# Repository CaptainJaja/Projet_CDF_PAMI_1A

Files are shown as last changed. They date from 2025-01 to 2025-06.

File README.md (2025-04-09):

# 🤖 Projet Coupe de France de Robotique 2025 – Design PCB 4 couches et Code STM32

Bienvenue sur le dépôt dédié à mon **design de PCB 4 couches** réalisé dans le cadre de la **Coupe de France de Robotique 2025** organisée par Planète Sciences.  
👉 [Site officiel](https://www.coupederobotique.fr/)

Je participe à cette aventure en tant qu'étudiant de **première année à l'ENSEA**, au sein de l'association **ARES Robotique**, avec une équipe composée également de deuxièmes années.

---

## 🧩 Description du PCB

Ce PCB a été conçu pour les **PAMI** (*Petits Actionneurs Mobiles Indépendants*), et intègre les fonctionnalités suivantes :

- 🧠 **Microcontrôleur :** STM32 L552CCT6
- ⚙️ **Driver moteur :** TB6612FNG
- 🚗 **2 connecteurs pour moteurs DC N20**
- 🔁 **2 connecteurs pour servomoteurs**
- 🧭 **1 connecteur pour module ultrason** (détection et évitement d'obstacles)
- ⚫ **1 connecteur pour module suiveur de ligne infrarouge 4 voies**
- 🔘 **Bouton reset**
- 🔌 **Pins GPIO, 3.3V, GND**
- 🔋 **Connecteur alimentation 7.4V (batterie Ni-Mh)**
- 🔧 **2 régulateurs DC-DC** (5V et 3.3V)
- 🔁 **Bobines, condensateurs, résistances**
- 🛠️ **Connecteur ST-Link** pour programmation et debug

---

## 🎬 Démos en GIF

### 🔩 PCB assemblé avec les composants soudés
GIF0 - Suiveur de ligne

### 🚗 Suiveur de ligne en action
GIF1 - PCB assemblé

---

## 🖼️ Vues des 4 couches du PCB

| Couche | Image |
|---|---|
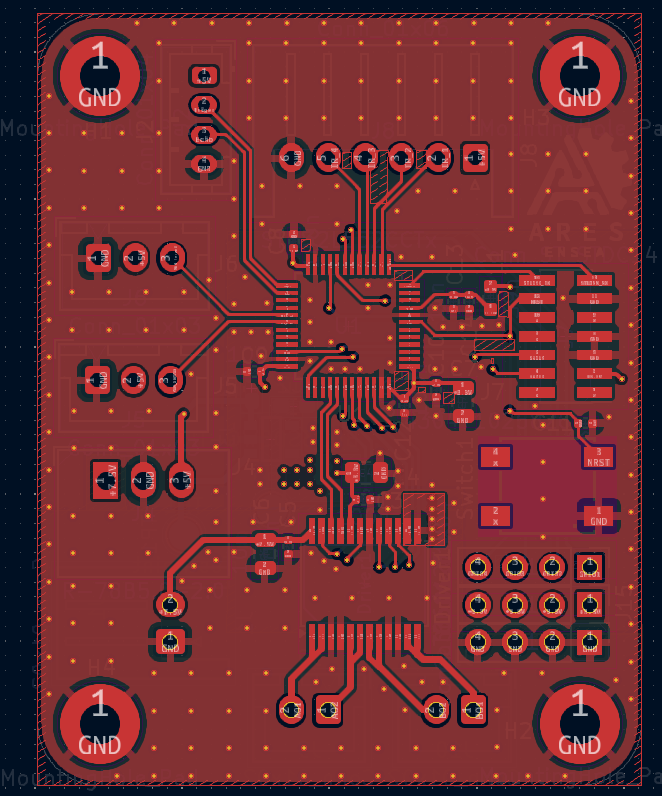
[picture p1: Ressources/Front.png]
Front
| **Face avant (Front)** |  |
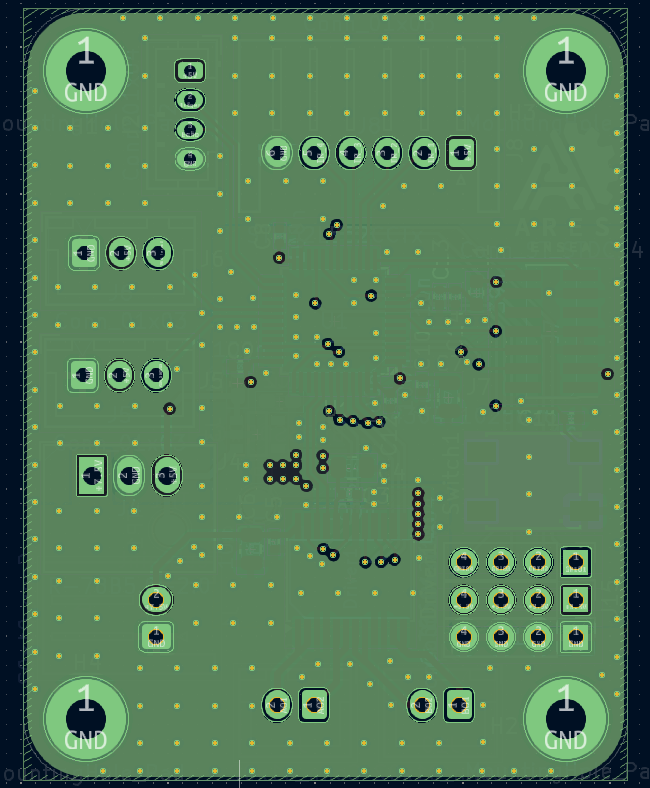
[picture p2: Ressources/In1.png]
In1
| **Plan de masse (In1)** |  |
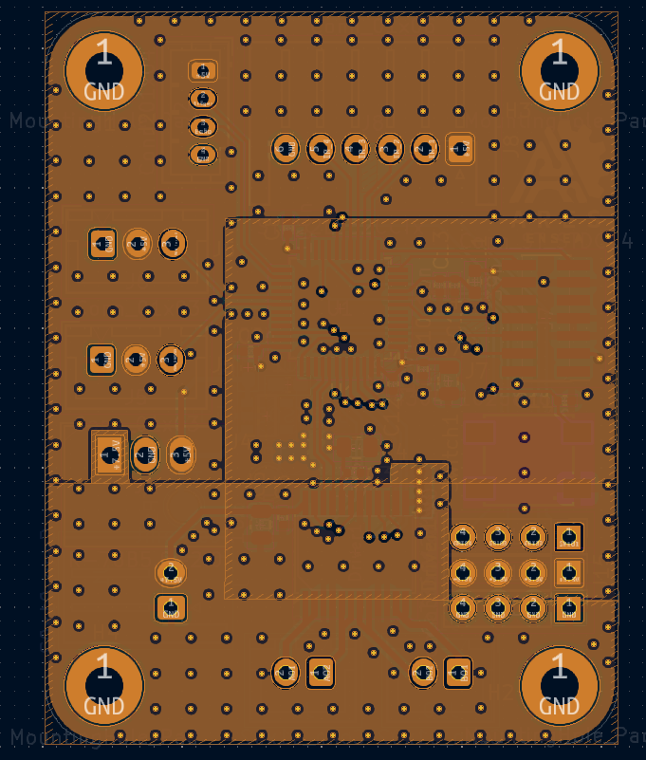
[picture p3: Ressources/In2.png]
In2
| **Plan d'alimentation (In2)** |  |
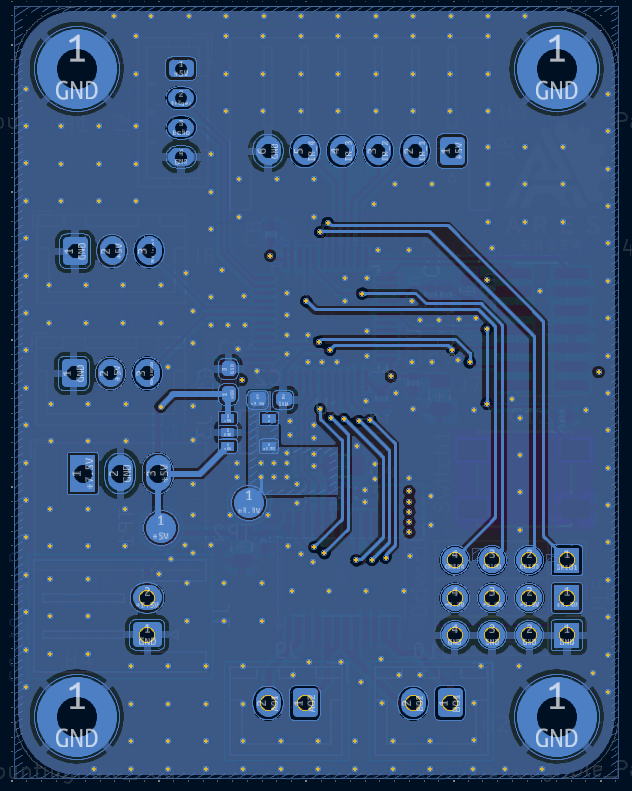
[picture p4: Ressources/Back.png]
Back
| **Face arrière (Back)** |  |

---

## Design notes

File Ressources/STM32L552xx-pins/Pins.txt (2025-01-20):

pour le STM32L552 en boîtier LQFP48 :

ADC12 : 
	   Pin num ; Pin name
* IN5= 		10 ; PA0
* IN6= 		11 ; PA1
* IN7= 		12 ; PA2
* IN8= 		13 ; PA3
* IN9= 		14 ; PA4
* IN10= 	15 ; PA5
* IN11= 	16 ; PA6
* IN12= 	17 ; PA7
* IN15= 	18 ; PB0
* IN16= 	19 ; PB1

Timers :
	   Pin num ; Pin name
*TIM2_CH1=	10 ; PA0 	(TIM5_CH1, USART, UART4_TX)
*TIM2_CH1=	15 ; PA5	(TIM2_ETR, TIM8_CH1N)
*TIM2_CH2=	11 ; PA1	(TIM5_CH2)
*TIM2_CH3=	12 ; PA2	(TIM5_CH3, TIM15_CH1, USART2_TX)
*TIM2_CH4=	13 ; PA3	(TIM5_CH4, TIM15_CH2, USART2_RX)
*TIM3_CH1=	16 ; PA6	(TIM1_BKIN, TIM8_BKIN, TIM16_CH1)
*TIM3_CH2=	17 ; PA7	(TIM1_CH1N, TIM8_CH1N, TIM17, CH1)
*TIM3_CH3=	18 ; PB0	(TIM1_CH2N, TIM8_CH2N)
*TIM3_CH4=	19 ; PB1	(TIM1_CH3N, TIM8_CH3N)
*TIM15_CH1=	27 ; PB14	(TIM1_CH2N, TIM8_CH2N)
*TIM1_CH1=	29 ; PA8	
*TIM1_CH2=	30 ; PA9
*TIM1_CH3=	31 ; PA10
*TIM1_CH4=	32 ; PA11
*TIM1_ETR=	33 ; PA12

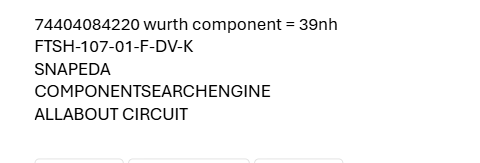
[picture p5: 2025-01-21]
Ressources/mail patricia.png

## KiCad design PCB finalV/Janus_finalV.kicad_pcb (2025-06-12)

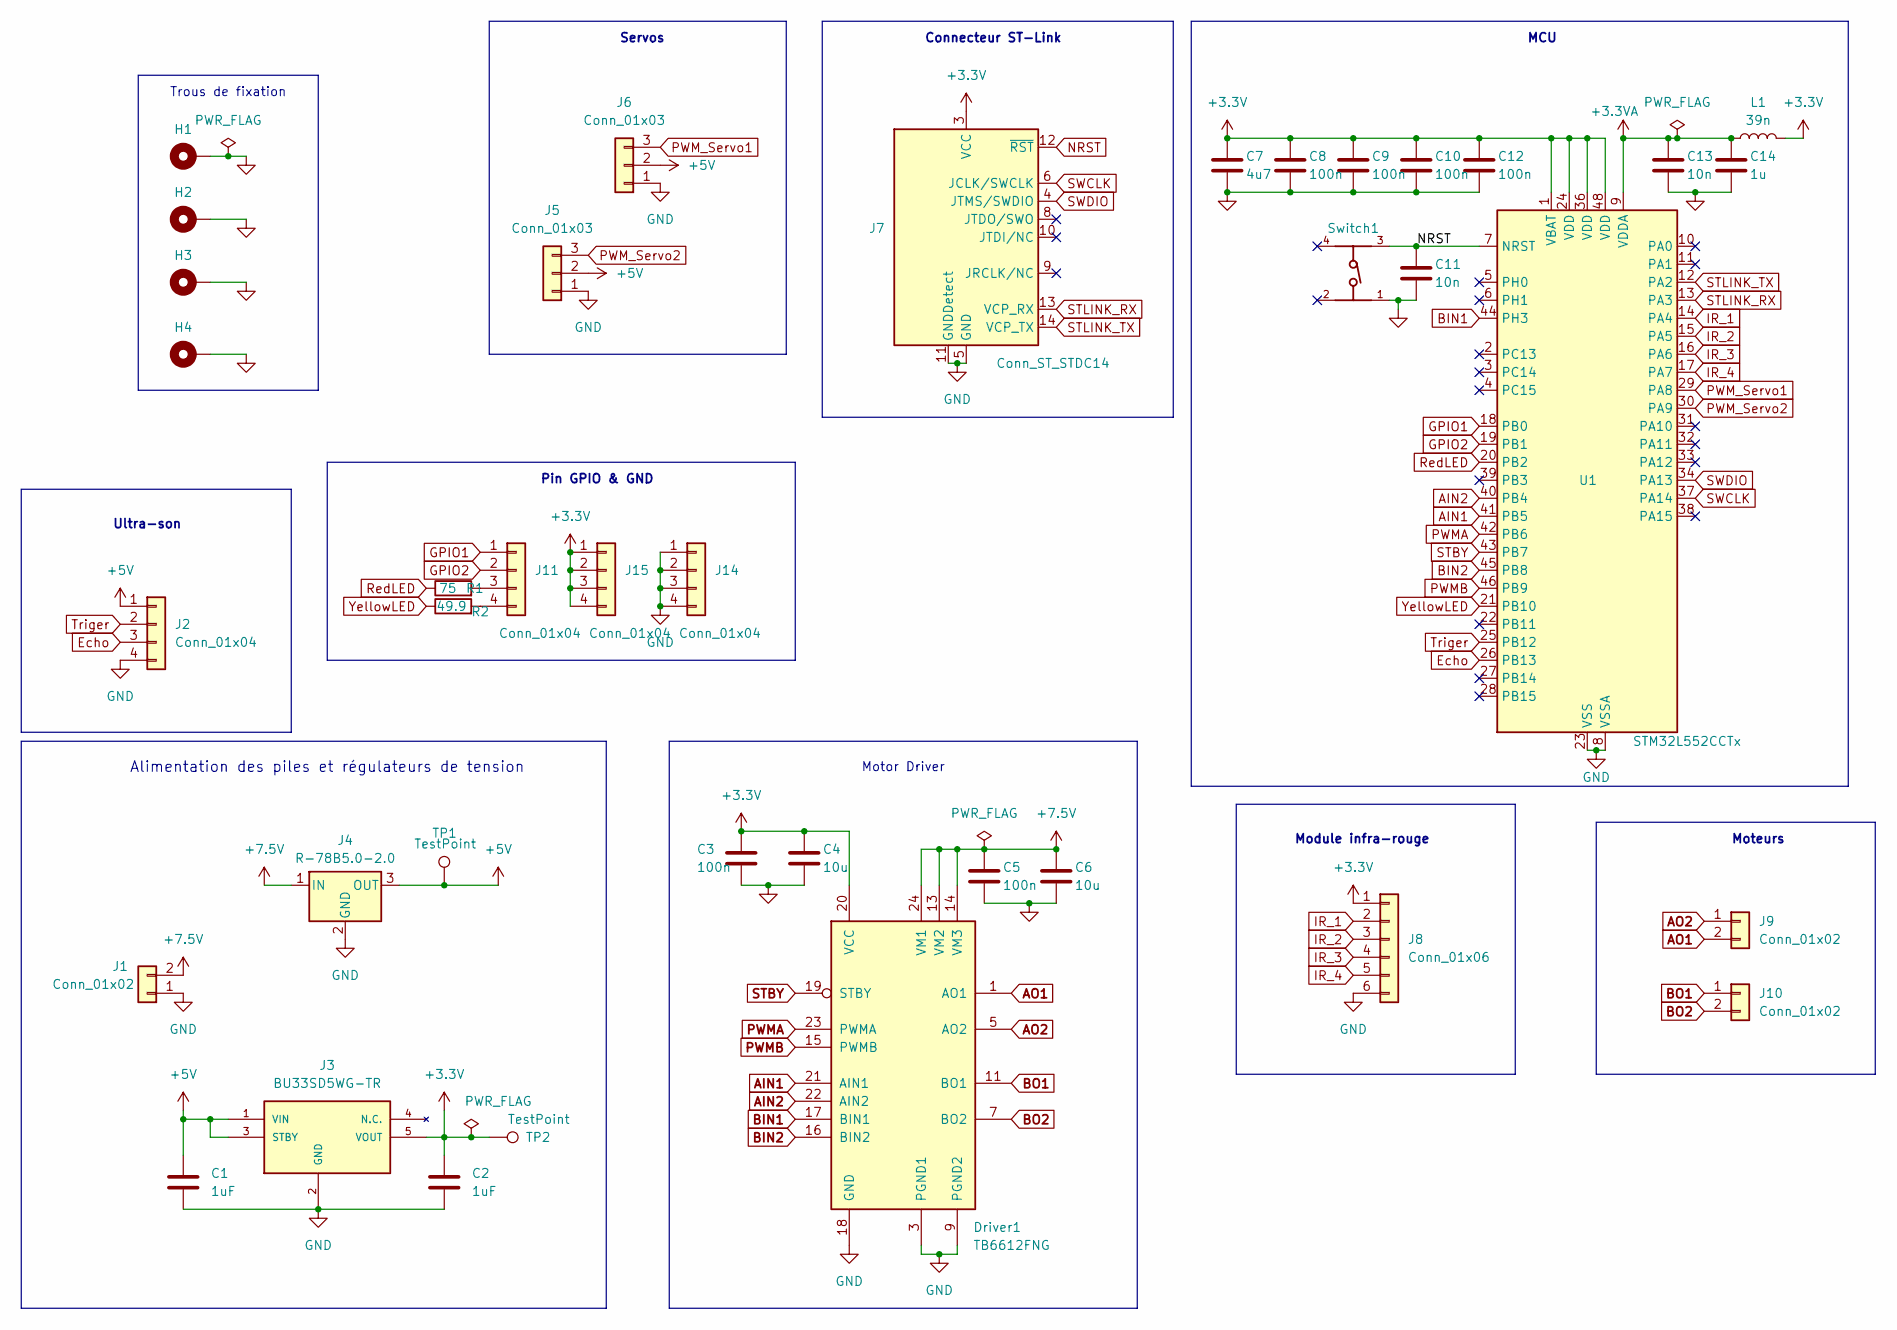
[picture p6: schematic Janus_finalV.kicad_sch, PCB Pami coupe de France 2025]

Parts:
C1, C2: 1uF; C_0603_1608Metric_Pad1.08x0.95mm_HandSolder
C3, C5, C8, C9, C10, C12: 100n; C_0402_1005Metric
C4, C6: 10u; C_0805_2012Metric
C7: 4u7; C_0805_2012Metric
C11, C13: 10n; C_0402_1005Metric
C14: 1u; C_0402_1005Metric
Driver1: TB6612FNG; SSOP-24_5.3x8.2mm_P0.65mm
H1, H2, H3, H4: MountingHole_Pad; MountingHole_2.7mm_M2.5_Pad
J1: Conn_01x02; JST_XH_S2B-XH-A-1_1x02_P2.50mm_Horizontal
J2: Conn_01x04; JST_PH_B4B-PH-K_1x04_P2.00mm_Vertical
J3: BU33SD5WG-TR; SOT95P280X125-5N; Mouser_Part_Number 755-BU33SD5WG-TR
J4: R-78B5.0-2.0; Converter_DCDC_RECOM_R-78B-2.0_THT
J5, J6: Conn_01x03; JST_XH_B3B-XH-A_1x03_P2.50mm_Vertical
J7: Conn_ST_STDC14; PinHeader_2x07_P1.27mm_Vertical_SMD
J8: Conn_01x06; JST_XH_S6B-XH-A-1_1x06_P2.50mm_Horizontal
J9, J10: Conn_01x02; JST_XH_B2B-XH-A_1x02_P2.50mm_Vertical
J11, J14, J15: Conn_01x04; PinHeader_1x04_P2.54mm_Vertical
L1: 39n; L_0603_1608Metric
R1: 75; R_0402_1005Metric_Pad0.72x0.64mm_HandSolder
R2: 49.9; R_0402_1005Metric_Pad0.72x0.64mm_HandSolder
Switch1: 430471025826; PART-NUMBER 430471025826
TP1, TP2: TestPoint; TestPoint_Pad_D2.0mm
U1: STM32L552CCTx; LQFP-48_7x7mm_P0.5mm

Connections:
+3.3V: C2.1, C3.1, C4.1, C7.1, C8.1, C9.1, C10.1, C12.1, Driver1.20 (VCC), J3.5 (VOUT), J7.3 (VCC), J8.1, J15.1, J15.2, J15.3, J15.4, L1.2, TP2.1, U1.1 (VBAT), U1.24 (VDD), U1.36 (VDD), U1.48 (VDD)
+3.3VA: C13.1, C14.1, L1.1, U1.9 (VDDA)
+5V: C1.1, J2.1, J3.1 (VIN), J3.3 (STBY), J4.3 (OUT), J5.2, J6.2, TP1.1
+7.5V: C5.1, C6.1, Driver1.13 (VM2), Driver1.14 (VM3), Driver1.24 (VM1), J1.2, J4.1 (IN)
AIN1: Driver1.21 (AIN1), U1.41 (PB5)
AIN2: Driver1.22 (AIN2), U1.40 (PB4)
AO1: Driver1.1 (AO1), Driver1.2 (AO1), J9.2
AO2: Driver1.5 (AO2), Driver1.6 (AO2), J9.1
BIN1: Driver1.17 (BIN1), U1.44 (PH3)
BIN2: Driver1.16 (BIN2), U1.45 (PB8)
BO1: Driver1.11 (BO1), Driver1.12 (BO1), J10.1
BO2: Driver1.7 (BO2), Driver1.8 (BO2), J10.2
Echo: J2.3, U1.26 (PB13)
GND: C1.2, C2.2, C3.2, C4.2, C5.2, C6.2, C7.2, C8.2, C9.2, C10.2, C11.2, C12.2, C13.2, C14.2, Driver1.3 (PGND1), Driver1.4 (PGND1), Driver1.9 (PGND2), Driver1.10 (PGND2), Driver1.18 (GND), H1.1, H2.1, H3.1, H4.1, J1.1, J2.4, J3.2 (GND), J4.2 (GND), J5.1, J6.1, J7.5 (GND), J7.7 (GND), J7.11 (GNDDetect), J8.6, J14.1, J14.2, J14.3, J14.4, Switch1.1, U1.8 (VSSA), U1.23 (VSS), U1.35 (VSS), U1.47 (VSS)
GPIO1: J11.1, U1.18 (PB0)
GPIO2: J11.2, U1.19 (PB1)
IR_1: J8.2, U1.14 (PA4)
IR_2: J8.3, U1.15 (PA5)
IR_3: J8.4, U1.16 (PA6)
IR_4: J8.5, U1.17 (PA7)
NRST: C11.1, J7.12 (~RST), Switch1.3, U1.7 (NRST)
unnamed: J11.3, R1.2
unnamed: J11.4, R2.2
PWMA: Driver1.23 (PWMA), U1.42 (PB6)
PWMB: Driver1.15 (PWMB), U1.46 (PB9)
PWM_Servo1: J6.3, U1.29 (PA8)
PWM_Servo2: J5.3, U1.30 (PA9)
RedLED: R1.1, U1.20 (PB2)
STBY: Driver1.19 (STBY), U1.43 (PB7)
STLINK_RX: J7.13 (VCP_RX), U1.13 (PA3)
STLINK_TX: J7.14 (VCP_TX), U1.12 (PA2)
SWCLK: J7.6 (JCLK/SWCLK), U1.37 (PA14)
SWDIO: J7.4 (JTMS/SWDIO), U1.34 (PA13)
Triger: J2.2, U1.25 (PB12)
YellowLED: R2.1, U1.21 (PB10)

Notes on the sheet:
Trous de fixation
Servos
Moteurs
Module infra-rouge
Connecteur ST-Link
Ultra-son
Alimentation des piles et régulateurs de tension
Motor Driver
Pin GPIO & GND
MCU

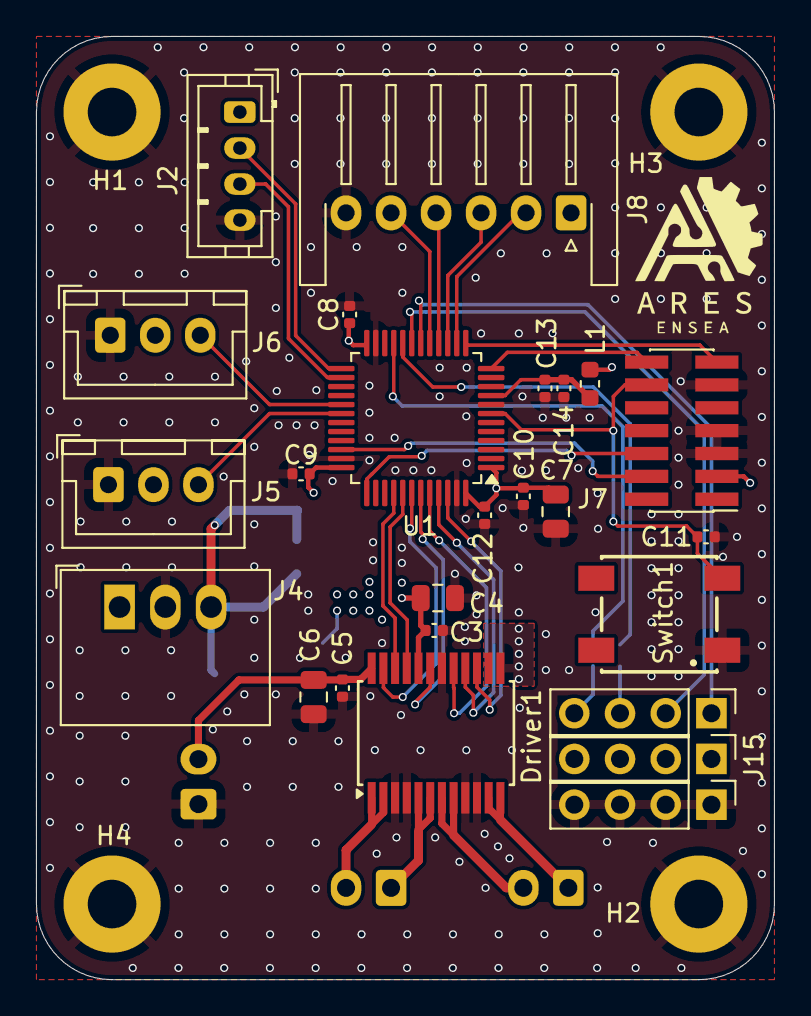
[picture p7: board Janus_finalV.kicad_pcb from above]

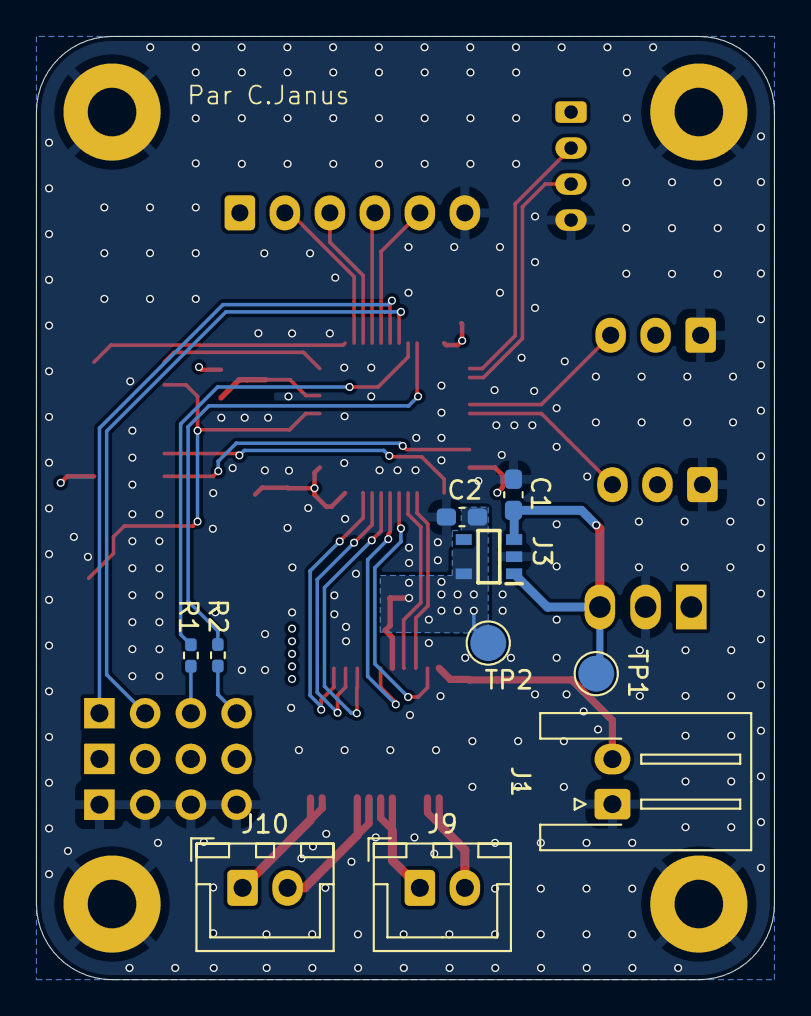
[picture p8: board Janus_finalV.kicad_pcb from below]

Board: 4 copper layers, 41.0 x 52.4 mm, 39 parts (10 on the bottom side), 35 nets.

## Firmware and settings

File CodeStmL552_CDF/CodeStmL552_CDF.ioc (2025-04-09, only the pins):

Mcu.UserName=STM32L552CCTx
PA2.Signal=USART2_TX
PA3.Signal=USART2_RX
PA4.GPIO_Label=X1
PA4.Signal=ADCx_IN9
PA5.GPIO_Label=X2
PA5.Signal=ADCx_IN10
PA6.GPIO_Label=X3
PA6.Signal=ADCx_IN11
PA7.GPIO_Label=X4
PA7.Signal=ADCx_IN12
PA8.GPIO_Label=Servo2
PA8.Signal=S_TIM1_CH1
PA9.GPIO_Label=Servo1
PA9.Signal=S_TIM1_CH2
PB0.GPIO_Label=Button
PB0.Signal=GPXTI0
PB12.GPIO_Label=TRIG
PB12.Signal=GPIO_Output
PB13.GPIO_Label=ECHO
PB13.Signal=GPXTI13
PB5.GPIO_Label=AIN1
PB5.Signal=GPIO_Output
PB6.GPIO_Label=PWMA
PB6.Signal=S_TIM4_CH1
PB7.GPIO_Label=STBY
PB7.Signal=GPIO_Output
PB8.GPIO_Label=BIN2
PB8.Signal=GPIO_Output
PB9.GPIO_Label=PWMB
PB9.Signal=S_TIM4_CH4
PH3-BOOT0.GPIO_Label=BIN1
PH3-BOOT0.Signal=GPIO_Output

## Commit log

2025-01-18 premier commit, ajout de deux répertoires et modification README
2025-01-18 ajout des notes dans les dossiers
2025-01-18 Update Note Karim.txt
    pour explique les nouveau termes qu'on connait pas
2025-01-20 Ajout dans Note Janus les pins pour le STM32L552 en boîtier LQFP48
2025-01-20 Ajout des pins pour ST-Link dans note Janus
2025-01-20 ajout du Kicad dans Dossier Janus
    [Projet_PAMI_Kicad.kicad_sch]
2025-01-20 ajout dossier+modif Kicad
    [Projet_PAMI_Kicad.kicad_pcb, Projet_PAMI_Kicad.kicad_sch]
2025-01-21 Finalisation schematic + ressources
    [Projet_PAMI_Kicad.kicad_sch]
2025-01-21 correction des oublies de numérotation de pins
    [Projet_PAMI_Kicad.kicad_sch]
2025-01-22 Finalisation PCB
    [Projet_PAMI_Kicad.kicad_pcb, Projet_PAMI_Kicad.kicad_sch]
2025-01-23 Finalisation du PCB--Dossier Janus
    [Projet_PAMI_Kicad.kicad_pcb, Projet_PAMI_Kicad.kicad_sch]
2025-01-24 Mise à jour couche d'alimentation
    [Projet_PAMI_Kicad.kicad_pcb, Projet_PAMI_Kicad.kicad_sch]
2025-02-04 ajout du répertoire Dossier Janus-bis contenant la version finale du PCB
    [Janus_finalV.kicad_pcb, Janus_finalV.kicad_sch, Projet_PAMI_Kicad.kicad_sch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]
2025-02-05 Update final Version
    [Janus_finalV-B_Cu.gbr, Janus_finalV-B_Mask.gbr, Janus_finalV-B_Paste.gbr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]
2025-03-17 update PCB1A
    [Janus_finalV-B_Cu.gbl, Janus_finalV-B_Mask.gbr, Janus_finalV-B_Mask.gbs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]
2025-04-09 selection dossier final
    [Janus_finalV-B_Cu.gbl, Janus_finalV-B_Mask.gbs, Janus_finalV-B_Paste.gbp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]
2025-04-09 modif nom dossier PCB
    [Janus_finalV-B_Cu.gbl, Janus_finalV-B_Mask.gbs, Janus_finalV-B_Paste.gbp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]
2025-04-15 MAJ code PAMI
    [Janus_finalV-B_Cu.gbl, Janus_finalV-B_Mask.gbs, Janus_finalV-B_Paste.gbp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]
